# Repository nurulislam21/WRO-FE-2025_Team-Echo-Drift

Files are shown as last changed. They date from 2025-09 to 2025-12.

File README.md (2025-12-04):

# Team Echo Drift - WRO Future Engineers 2025
Loading Echo Drift Cover Banner...






---

**Welcome** to the official GitHub repository of **Team Echo Drift**!

This project showcases our autonomous robot for **WRO Future Engineers 2025**, built to navigate using only **camera**, **gyro**, and **encoder** data. We implement computer vision with **OpenCV**, **PID control**, and sensor data analysis in **MATLAB** to achieve precise and reliable navigation.

Explore the repository to learn more about our system design, documentation, and code!

# Table of Contents  

---

### Ⅰ. [About the Team](#about-the-team)  
### Ⅱ. [Competition Overview](#competition-overview)  
### Ⅲ. [Our Robot](#our-robot)  
### Ⅳ. [System Architecture](#system-architecture)  
### Ⅴ. [Hardware Components](#hardware-components)  
### Ⅵ. [Software & Algorithms](#software--algorithms)  
### Ⅶ. [CAD & Mechanical Design](#cad--mechanical-design)  
### Ⅷ. [Electronics & Wiring](#electronics--wiring)  
### Ⅸ. [Testing & Validation](#testing--validation)  
### Ⅹ. [Results & Performance](#results--performance)  
### Ⅺ. [Future Improvements](#future-improvements)  
### Ⅻ. [How to Run the Code](#how-to-run-the-code)  
### XIII. [Contributors](#contributors)  
### XIV. [License](#license)  

---
## About the Team  

We’re three young innovators from across Bangladesh, brought together by our love for robotics and tech. We first met as solo competitors sharing ideas, dreams, and soon a vision. That’s how our team was born.

<!-- Noman -->
<table>
  <tr>
    <td>
<h2> Noman - Mechanical Engineering </h2>

Specialized in Mechanical Design with experience in SolidWorks, Fusion 360, for 3D modeling. Strong background in robotics and embedded systems, 
supported by hands-on R&D work. Experience in robotics and embedded systems supports a well-rounded engineering approach, enabling the design of precise, reliable, and integrated mechanical solutions.
<br/> <br/>
_Github: [github.com/nurulislam21](https://github.com/nurulislam21/)_
    </td>
    <td>
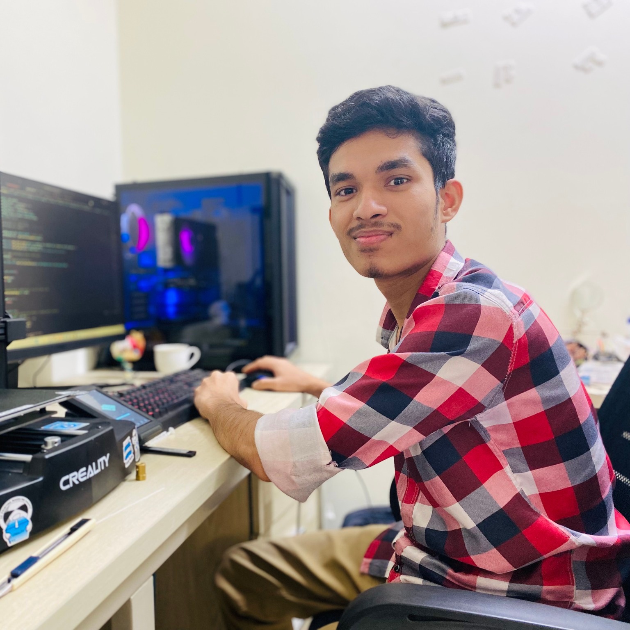
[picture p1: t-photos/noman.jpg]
Nurul Islam Noman
      
    </td>
  </tr>
</table>

<!-- Tanim SK -->
<table>
  <tr>
    <td>
<h2> Tanim - Programming & Software Architecture </h2>

Skilled in Python, C++, JavaScript, OpenCV-based computer vision, Python Matplotlib and NumPy with experience in robotics, embedded systems, Raspberry Pi, microcontrollers, PlatformIO, and building user interfaces (web & tkinter).
<br/> <br/>
_Github: [github.com/tanimsk](https://github.com/tanimsk/)_
    </td>
    <td>
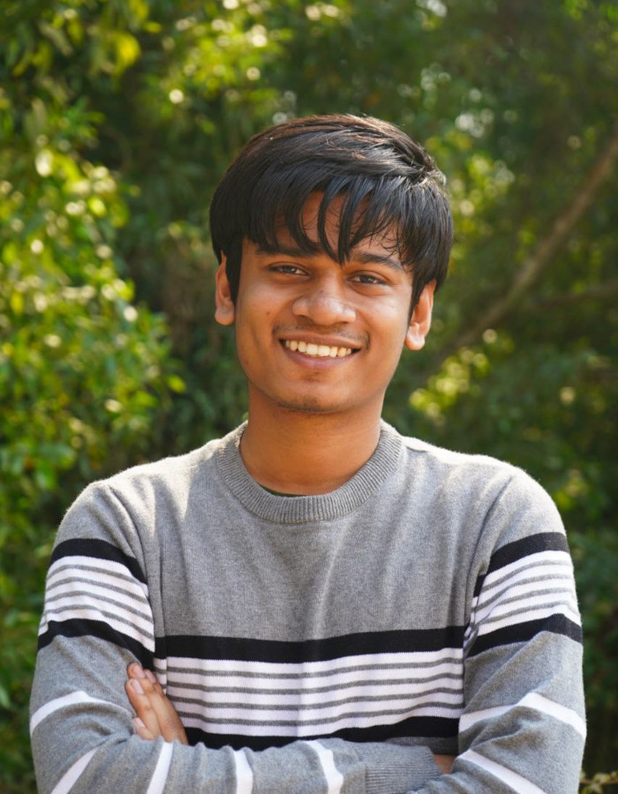
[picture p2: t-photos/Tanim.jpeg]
Tanim SK
      
    </td>
  </tr>
</table>

<!-- Majedul Islam Naeem -->
<table>
  <tr>
    <td>
<h2> Majedul Islam Naeem - Electronics & Circuit Design </h2>

Electronics and circuit design specialist with PCB experience in EasyEDA and Altium. Skilled in etching-based PCB fabrication, soldering, prototyping, troubleshooting, and hardware testing.
<br/> <br/>
_Github: [github.com/majednaeem](https://github.com/majednaeem/)_
    </td>
    <td>
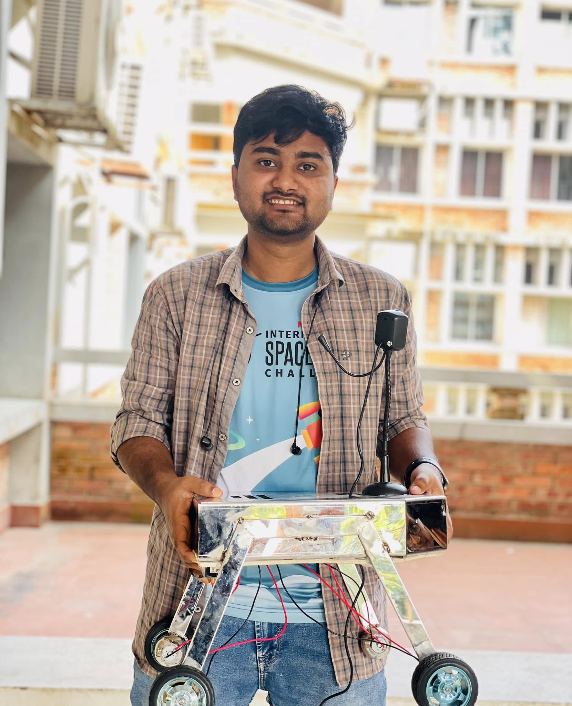
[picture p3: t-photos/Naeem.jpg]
Majedul Islam Naeem
      
    </td>
  </tr>
</table>

---

## Navigation Menu
- [Project Overview](#project-overview)
- [Hardware Design & Gear System](#hardware-design--gear-system)
- [Differential Gear Mechanism](#differential-gear-mechanism)
- [Differential Gear Conversion](#differential-gear-conversion)
- [Software Architecture](#software-architecture)
- [Setup & Dependencies](#setup--dependencies)
- [Video Demonstration](#video)
- [Project Structure](#project-structure)
- [Resources & Media](#resources--media)

---

## Competition Overview  

WRO **Future Engineers** challenges teams to design autonomous electric vehicles (EVs) that can:  

- Navigate track autonomously
- Avoid obstacles and maintain a safe distance from the boundaries
- Parking out and parking out of a designated zone

---

<h2> Competition Rounds </h2>

The WRO Future Engineers 2025 competition is divided into **two progressive rounds**. Each round adds new layers of complexity and pushes teams to demonstrate engineering excellence.  

| Round | Description | Key Tasks | Track Layout |
|:---|:---:|:---|:---|
| **Round 1 - Open Challenge** | Focuses on **precise navigation and lap consistency**. The robot must complete **3 laps** maintaing safe distance from the boundary walls. Judges emphasize **stability, accuracy, and precise lane following**. | - Focus on **stability, accuracy, and smooth lane following**  <br> - Complete **3 full laps** without error | |
| **Round 2 – Obstacle Challenge** |  The robot must avoid **color-coded obstacles** (from specific direction) and then park in a **designated zone** after **3 laps**.| - 🟩 **Green obstacle → move left**  <br> - **🟥 Red obstacle → move right**  <br> -  Maintain speed while **avoiding collisions**   <br> - Finish with **precision parking** inside a marked box  |   |

> **Both rounds are aligned with the [official WRO 2025 Future Engineers Rules (PDF)](https://wro-association.org/wp-content/uploads/WRO-2025-Future-Engineers-Self-Driving-Cars-General-Rules.pdf).**

---

## Our Robot
### Robot Overview  
**Echo Drift** brings a **Vision guided Robot** to WRO 2025, built for speed, accuracy, and adaptability.
  
- Precise track navigation  
- Real-time obstacle avoidance  
- Controlled drift manoeuvres
- Odometry analysis from gyro and encoder

🛠️ 3D-printed chassis | 🔌 Smart sensors & drivers | 🧠 Vision & PID control

---

## 📊 Robot Specifications 

| Parameter | Value |
|---|---|
| *Dimensions* | 20 cm (L) × 11 cm (W) × 25 cm (H) |
| *Weight* | ~ 0.7 kg |
| *Chassis* | Modular 3D-printed PLA with reinforced mounts |
| *Motors* | N20 motor  |
| *Motor Driver* | TB6612FNG dual-channel |
| *Steering* | MG90S Servo |
| *Sensors* | IMU, Encoder |
| *Camera* | OV5647 Fish eye 160° wide angle Camera |
| *Controller* | Raspberry Pi 5 (8GB) |
| *Battery* | 3S 11.1V Li-Po, 2200mAh |
---

## 📸 Vehicle Photos  

| Front | Right | Back |
|---|---|---|
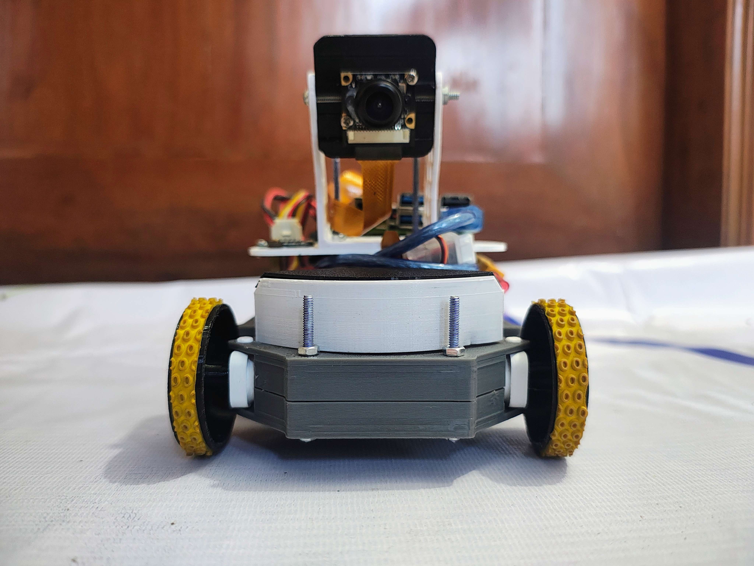
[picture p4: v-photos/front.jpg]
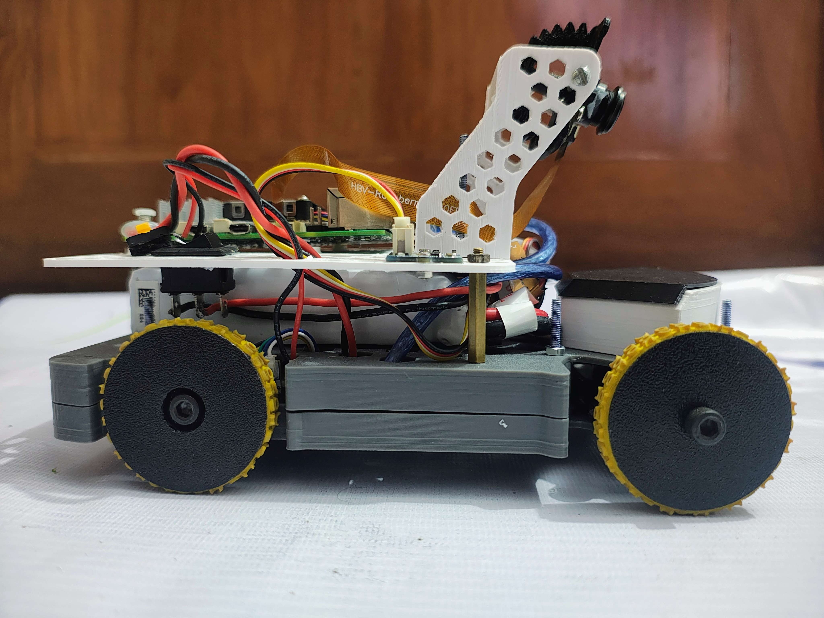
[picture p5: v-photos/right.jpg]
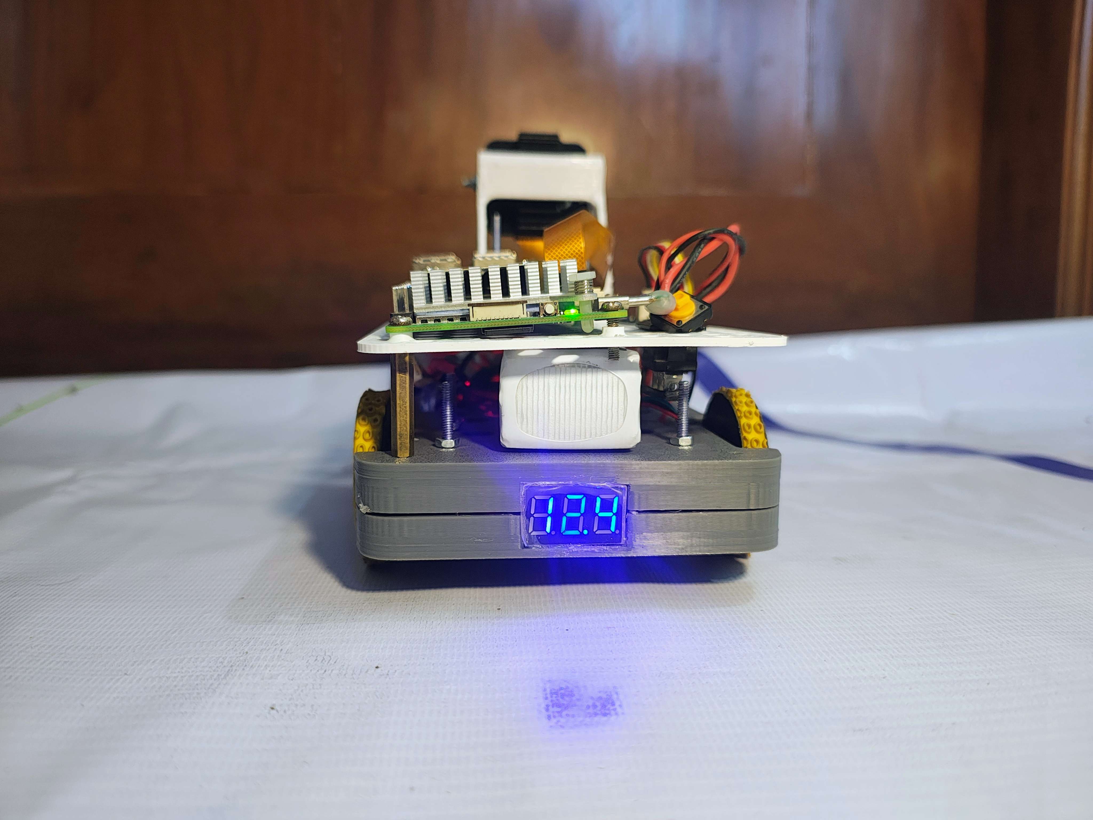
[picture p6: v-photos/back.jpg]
|  |  |  |

| Left | Top | Bottom |
|---|-----|---|
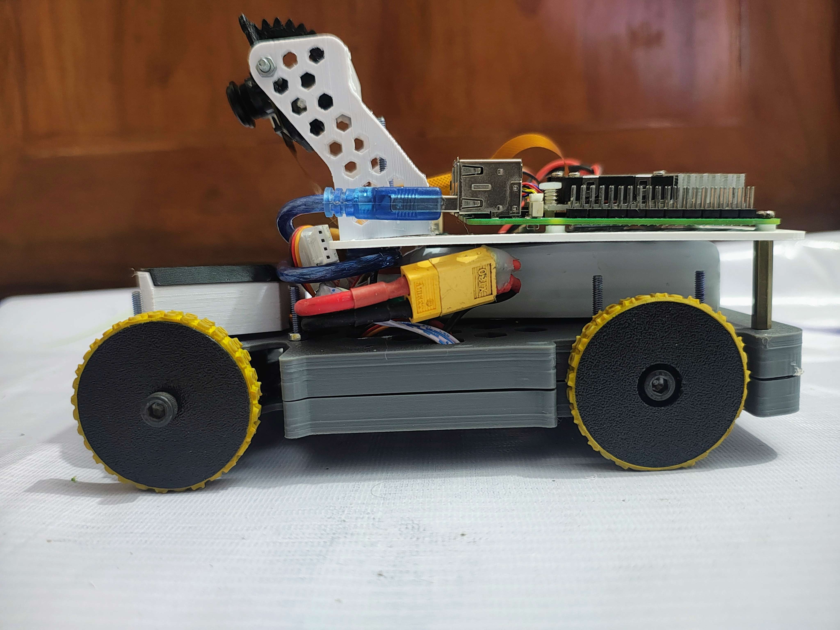
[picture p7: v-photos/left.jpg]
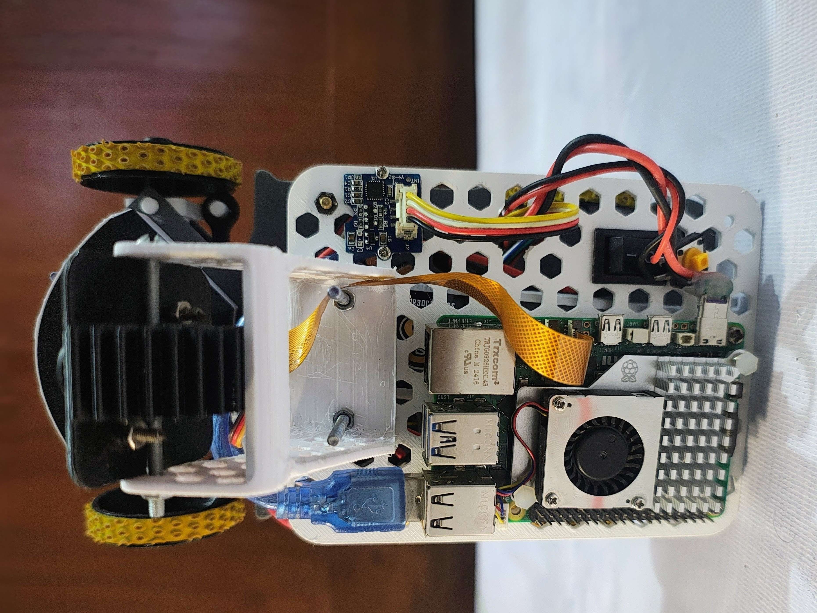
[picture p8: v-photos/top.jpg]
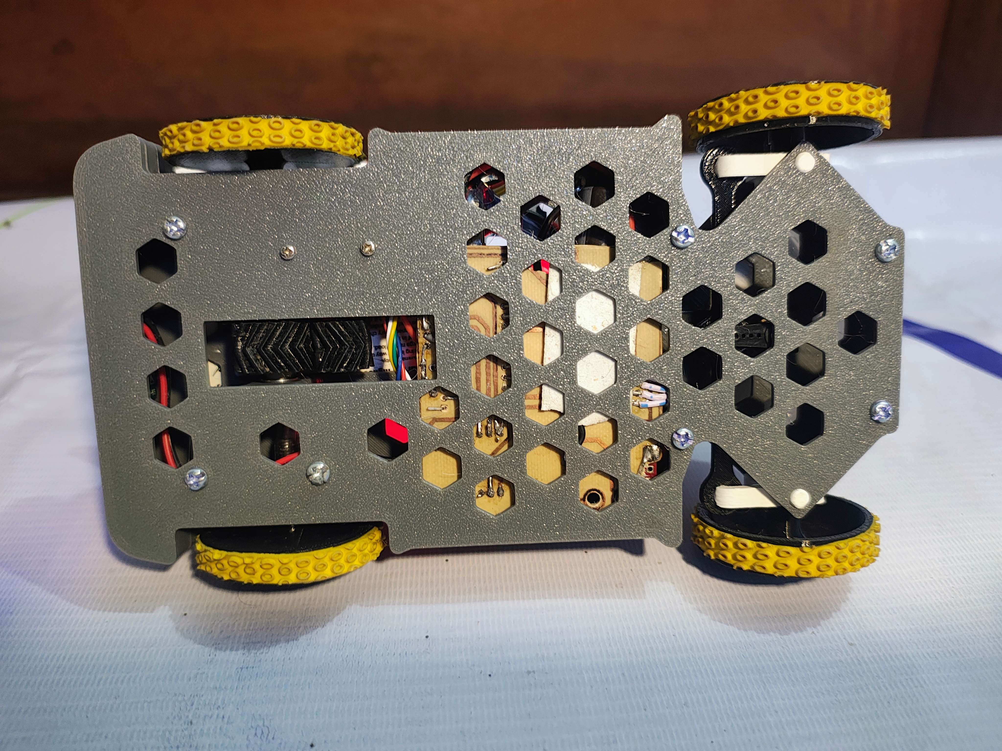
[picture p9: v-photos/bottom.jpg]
|  |  |  |

---

## 🎥 Videos of Our Robot  

Test Run 1 – Track Navigation (https://www.youtube.com/watch?v=hIYXWFPvM-o)

Test Run 2 – Track Navigation, Object avoidance & Parking out (https://www.youtube.com/watch?v=Nrufbg69Ze8)

---

## System Architecture  

  

---

## Layered Architecture Overview 

| *Layer* | *Key Components* | *Role & Engineering Considerations* |
| --- | --- | --- |
| *Hardware* | - PLA + Aluminum Hybrid Chassis  <br> - 1× DC Geared Motors (12V, 600RPM, 1.2Nm)  <br> - High-Torque Servo (15kg·cm)  <br> - 65mm Rubberized Wheels | - Rigid but lightweight frame ensures stability and durability. <br> - Motor torque chosen with ~30% safety margin for acceleration under load. <br> - Servo provides precise steering with quick response. <br> - Wheel diameter selected for a balance between speed and traction. |
| *Power* | - 3S LiPo (11.1V, 2200mAh)  <br> - Power Distribution Board (12V, 5V outputs)  <br> - XT60 Connectors | - LiPo selected for high discharge rate, lightweight, and compact size. <br> - Separate regulated lines prevent voltage drop issues. <br> - XT60 provides short-circuit and overload safety. |
| *Perception* | - Camera <br> - Gyro <br> - Encoder | - Camera handles *lane detection and vision-based markers*. <br> - IMU improves orientation and stability on turns. <br> - Encoders provide real-time speed & distance for closed-loop control. |
| *Control & Processing* | - Raspberry Pi 5 (Python + OpenCV)  <br> - Arduino Nano (C++)  <br> - UART Serial Link | - Pi processes camera input & makes high-level decisions. <br> - Arduino handles *PWM signals, interrupts, and motor control* with real-time precision. <br> - UART ensures fast, low-latency communication between subsystems. |
| *Decision* | - OpenCV Line Detection  <br> - Sensor Fusion (Camera)  <br> - PID Steering Control  <br> - Encoder-based Speed Feedback  <br> - Emergency Stop Failsafe | - Lane tracking optimized with *real-time vision algorithms*. <br> - Sensor fusion improves obstacle avoidance accuracy. <br> - PID ensures smooth steering corrections. <br> - Encoders maintain consistent velocity. <br> - Safety protocol: robot halts when conflicting data is detected. |
| *Actuation* | -  Motor Driver <br> - PWM Servo Driver | - H-Bridge supplies bidirectional control for drive motors. <br> - Servo driver ensures precise angle control. <br> - Final output: *smooth differential drive with adaptive steering*. |
---

## Threads & Rates
| Task | Rate | Notes |
| --- | ---: | --- |
| Sensor read  |  50–100 Hz | median filter, timeouts |
| Vision |  20–30 FPS | HSV masks for lane & pillar colors |
| Fusion | 50 Hz | complementary/Kalman (optional) |
| Navigation | 20–50 Hz | lane-keeping, color rule, parking  |
| Control | 100–200 Hz | PID for speed + steering |

---

## Hardware & Mechanical Part
Our robot is designed with a balanced mix of mechanical, electrical, and electronic components, ensuring rule compliance (size, weight, drive system) and performance (precision, stability, obstacle avoidance).

### List of components

| Component | Image | Qty | Notes |
|---|---|-----|---|
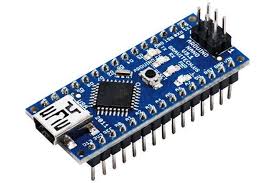
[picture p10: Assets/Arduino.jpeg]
| **Arduino Nano** |  | x1 | Microcontroller for low-level control |
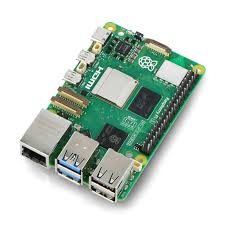
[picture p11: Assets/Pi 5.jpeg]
| **Raspberry Pi 5** |  | x1 | Main controller for vision & navigation |
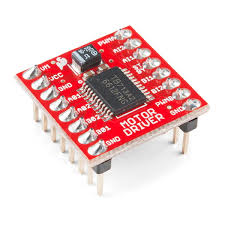
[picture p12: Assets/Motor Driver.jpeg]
| **TB6612FNG Motor Driver** |  | x1 | Controls DC motors |
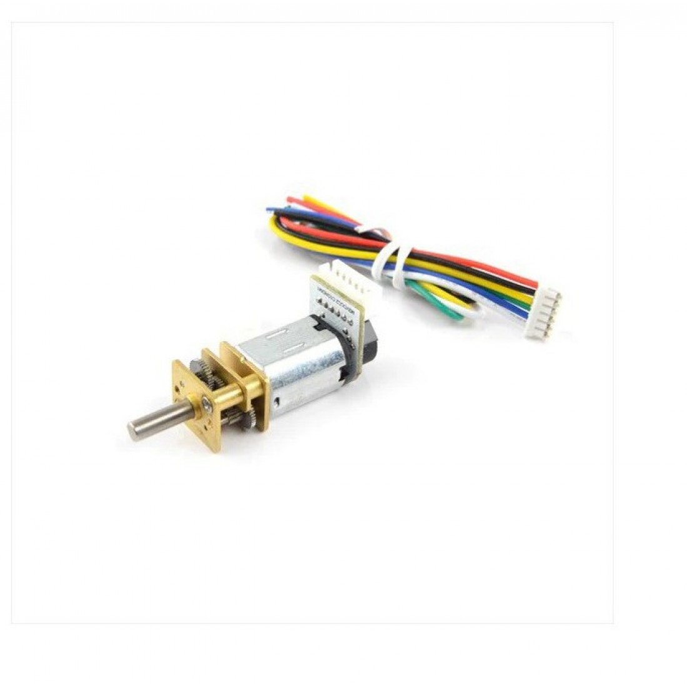
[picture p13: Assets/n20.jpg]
| **N20 DC Gear Motors (12V) with encoder** |  | x2 | Linked to rear axle |
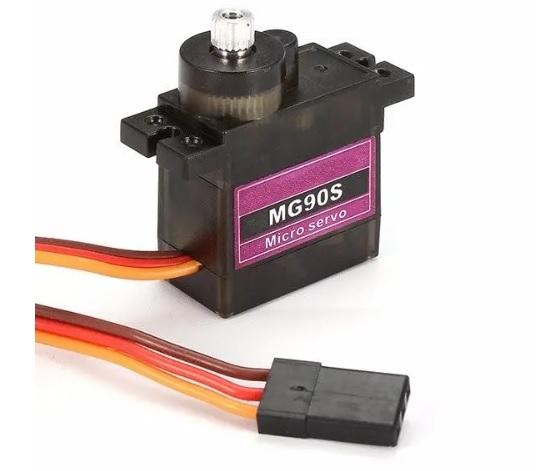
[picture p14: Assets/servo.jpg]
| **MG90s Servo** |  | x1 | For front wheel steering |
| **IMU MPU6050 Gyroscope** |  | x1 | Orientation & stability |
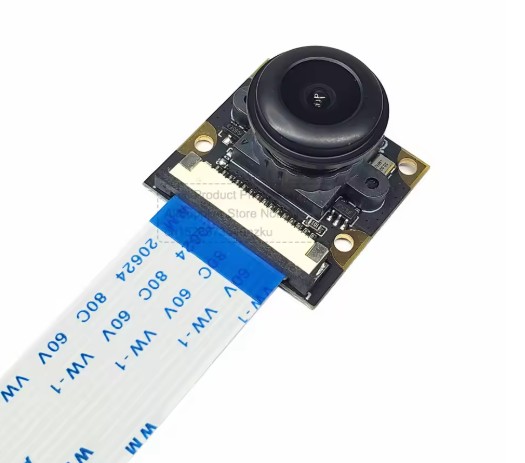
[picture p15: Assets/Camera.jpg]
| **OV5647 Camera Module for Raspberry Pi** |  | x1 | Lane & obstacle detection |
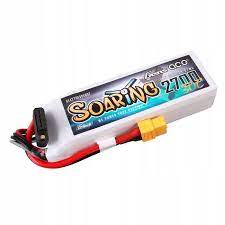
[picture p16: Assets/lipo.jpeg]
| **Li-Po Battery (3S, 11.1V, 2200mAh)** |  | x1 | Main power source |
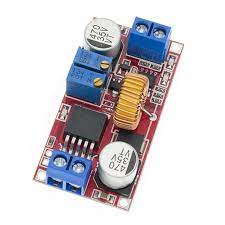
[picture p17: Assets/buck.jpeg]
| **XL4015 Step-down Converter** |  | x1 | Voltage regulation |
| **Prototype PCB Board** | PCB | x1 | Custom wiring layout |
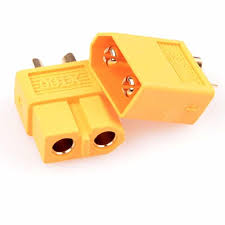
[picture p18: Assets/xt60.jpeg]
| **XT60 Connector** |  | x1 |  Main power control |
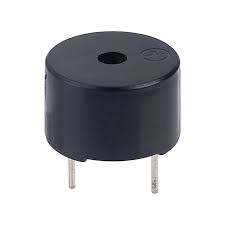
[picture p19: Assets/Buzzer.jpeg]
| **Buzzer** |  | x1 |Line Status Check |

## Mobility Management
Mobility management defines how the robot moves, steers, and maintains stability. For Echo Drift, we adopted a rear-wheel drive + front servo steering configuration. This gives better maneuverability, efficient obstacle avoidance, and realistic car-like motion.

### Motor Selection 

#### Drive Motors
- **Type:** N20 DC Geared Motors with Encoders  
- **Specs:** 12V, ~600 RPM, ~1.2 Nm torque  
- **Reason:** Higher speed compared to 300 RPM version. Encoders provide feedback for closed-loop control (speed & distance). Torque margin (~30% extra) ensures reliable acceleration.

#### Steering Servo
- **Type:** High-torque Servo (~1.8 kg·cm)  
- **Reason:** Quick, precise steering even under load.

#### Engineering Principle
Torque Required = Wheel Radius × Force (Load + Friction)

- Our calculation showed motor Required torque ≈ **0.9 Nm**  
- Selected N20 motors rated ≈ **1.2 Nm** → safe margin  
- Speed doubles from ~1.0 m/s (300 RPM) to ~2.0 m/s (600 RPM) on 45 mm wheels.

📂 Encoders connected to Arduino for speed control and stability.

| Drive Motors (N20 with Encoders) | Steering Servo Assembly |
|---|---|
| | |

## Hardware Design & Gear System

The hardware design balances **mechanical precision** with **reliable electronics**.

**Key features:**
- **Drive System:** N20 encoder motor + TB6612FNG driver for smooth torque

- **Steering:** Parallel steering system with MG90S servo for steering control  
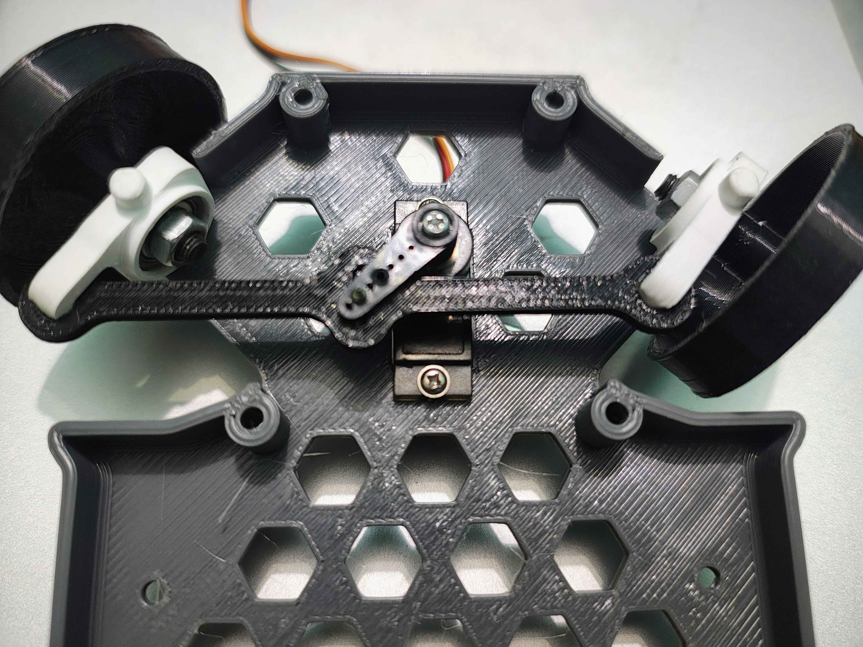
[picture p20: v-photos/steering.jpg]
Steering


- **Differential Gear:** WL Toys differential gear with bearing
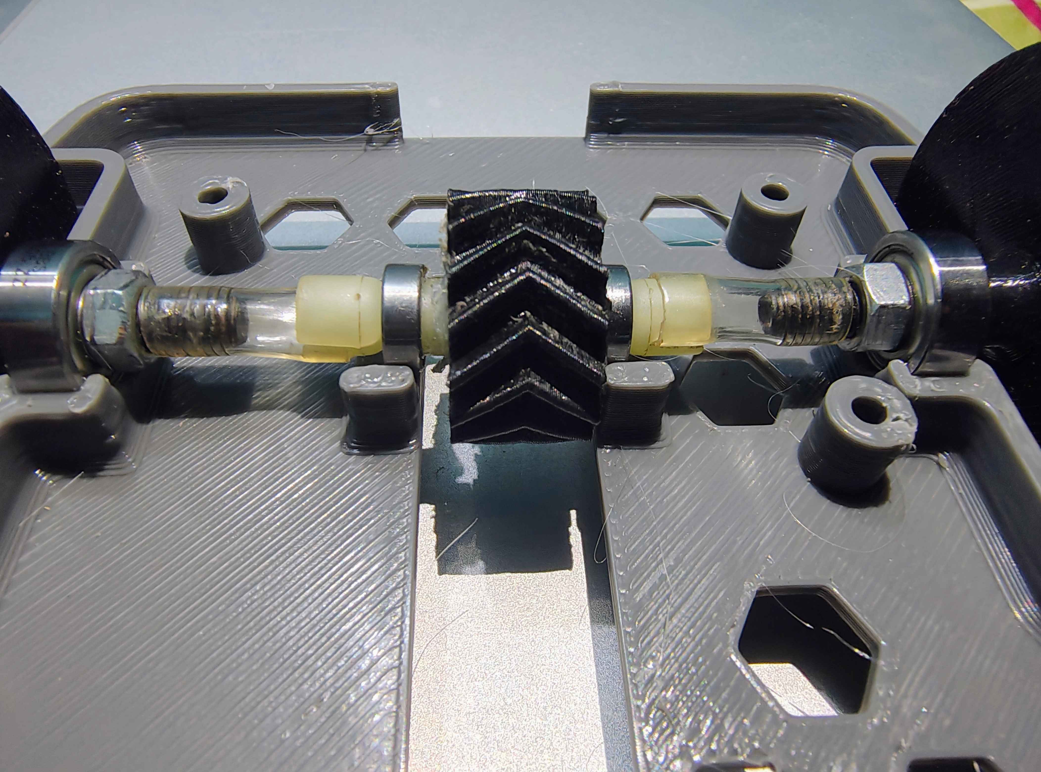
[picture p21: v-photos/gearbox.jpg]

  
- **Chassis:** Fully 3D-printed (SolidWorks STL); lightweight yet strong
SolidWorks Design
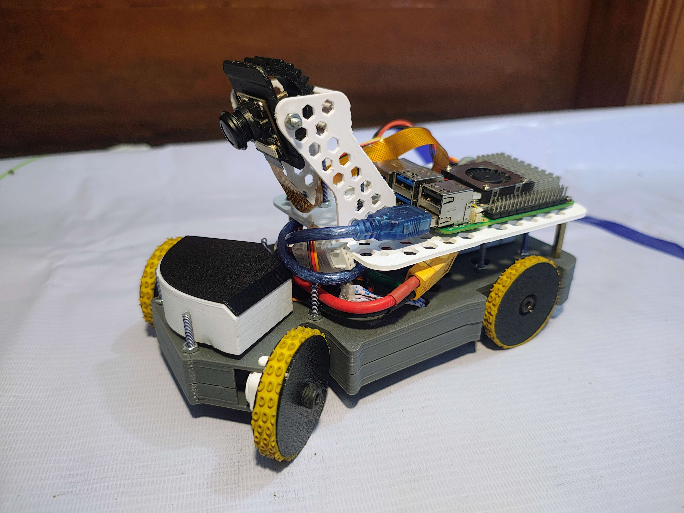
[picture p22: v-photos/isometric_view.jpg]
Vehicle Side View


- **ND filter for camera**: We later mounted an ND filter in front of the camera to maintain consistent lighting in bright environments. By tuning the ND filter, we were able to reduce glare and stabilize exposure, ensuring more reliable image processing.
<p align="center">
  
  
</p>

---

## Software Architecture

<p align="center">
  Software Flowchart
</p>

---

## Setup & Dependencies

| Category | Details |
|---|---|
| **Operating System** | Raspberry Pi OS, Ubuntu 20.04 |
| **Programming Languages** | C, C++, Python |
| **Compiler** | GCC |
| **Libraries (C/C++)** | WiringPi, bcm2835 |
| **Build Tools** | Make, GCC toolchain |
| **Python Packages** | simple-pid, opencv-python, numpy, matplotlib, pillow, pyserial |
| **Arduino Development Platform** | PlatformIO |

**Install Dependencies:**
```bash
sudo apt update && sudo apt upgrade -y
sudo apt install build-essential git make -y

# WiringPi
git clone https://github.com/WiringPi/WiringPi
cd WiringPi && ./build && cd ..

# bcm2835
wget http://www.airspayce.com/mikem/bcm2835/bcm2835-1.71.tar.gz
tar zxvf bcm2835-1.71.tar.gz
cd bcm2835-1.71
./configure && make
sudo make check
sudo make install
cd ..

# clone our repository
git clone https://github.com/nurulislam21/WRO-FE-2025_Team-Echo-Drift/
cd WRO-FE-2025_Team-Echo-Drift/src
# install the dependencies
pip install -r requirements.txt

# run the program
# for open challenge
python raspberrypi/open_challenge.py --debug

# for obstacle challenge
python raspberrypi/obstacle_challenge.py --debug

# for starting the program on startup, register it as a service or a crontab

```

We have divided the whole frame into 6 segments, each segment runs a seperate image processing thread.

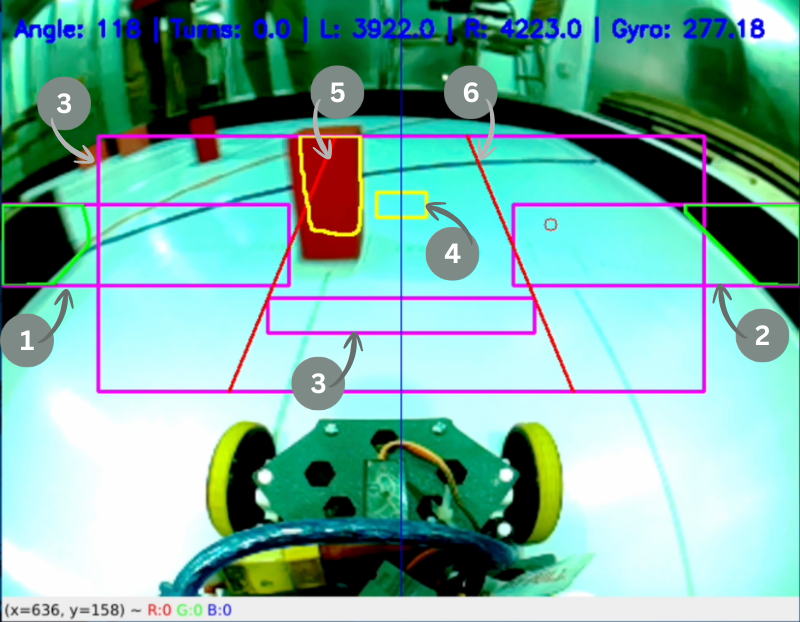
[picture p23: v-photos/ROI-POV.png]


ROI Partition Explanation:
```
1. Left Wall Region: Detects the left boundary wall for lane-keeping.
2. Right Wall Region: Detects the right boundary wall for lane-keeping.
3. Reverse Region: Detects if obstacles/walls are too close.
4. Front wall Region: Detects frontal wall.
5. Left Danger Zone: Monitors for red obstacles on the right side.
6. Right Danger Zone: Monitors for green obstacles on the left side.
```

The frame regions are assigned here:

```py
# Region of Interest coordinates
LEFT_REGION = [20, 220, 270, 280]
RIGHT_REGION = [370, 220, 620, 280]
OBS_REGION = [85, 140, 555, 320]
REVERSE_REGION = [233, 300, 407, 320]
FRONT_WALL_REGION = [300, 195, 340, 215]
PARKING_LOT_REGION = [0, 185, CAM_WIDTH, 400]
DANGER_ZONE_POINTS = [
    {
        "x1": 302,
        "y1": OBS_REGION[1],
        "x2": 205,
        "y2": OBS_REGION[3],
    },
    {
        "x1": 350,
        "y1": OBS_REGION[1],
        "x2": 435,
        "y2": OBS_REGION[3],
    },
]
```

<br>

We are using LAB colors for detecting a object based on a certain color range, the color ranges are assigned as numpy arrays in [main.py](https://github.com/nurulislam21/WRO-FE-2025_Team-Echo-Drift/blob/main/src/raspberrypi/main.py):

```py
# Color ranges
LOWER_BLACK = np.array([0, 108, 90])
UPPER_BLACK = np.array([89, 148, 163])

LOWER_ORANGE = np.array([135, 125, 83])
UPPER_ORANGE = np.array([195, 165, 123])

LOWER_BLUE = np.array([93, 144, 164])
UPPER_BLUE = np.array([153, 184, 204])

# obstacle color ranges HSV
LOWER_RED = np.array([160, 100, 200])
UPPER_RED = np.array([180, 255, 255])

# HSV
LOWER_GREEN = np.array([35, 100, 50])
UPPER_GREEN = np.array([85, 255, 255])

# parking color ranges
LOWER_MAGENTA = np.array([100, 81, 105])
UPPER_MAGENTA = np.array([170, 121, 145])
```

<br>

Then we made a class called `ContourWorkers.py` in [contour_workers.py](https://github.com/nurulislam21/WRO-FE-2025_Team-Echo-Drift/blob/main/src/raspberrypi/contour_workers.py), this class is used to get contours based on the passed color ranges. ContourWorker starts 6 seperate thread for 6 regions, and processes them individually. Thus we are able to keep a decent FPS (around 25) while our bot is on the go. We are using `Queue` with size of 2 to make sure our frames are queued and passed to the thread and processed accordingly:

```py
# queues
self.frame_queue_left = Queue(maxsize=2)
self.frame_queue_right = Queue(maxsize=2)
self.frame_queue_orange = Queue(maxsize=2)
self.frame_queue_blue = Queue(maxsize=2)
self.frame_queue_green = Queue(maxsize=2)
...
```

<br>

After that, we were facing an issue for motion blur due to speed. We've resolved this issue by setting explicit `Exposure rate` and `Analogue gain`, and disabling `Auto Exposure` & `Auto white balance` in our camera configuration:



<br>

```py
picam2.set_controls(
    {
        "ExposureTime": 16000,
        "AnalogueGain": 42.0,
        "AeEnable": False,
        "AwbEnable": False,
        "FrameDurationLimits": (40000, 40000),
    }
)
```

<br>

After the program is executed, we start 6 threads, and inside while loop, we are collecting the contour result in each iteration:

```py
# Retrieve all results from queues (non-blocking)
(
    left_result,
    right_result,
    green_result,
    red_result,
    reverse_result,
    front_wall_result,
) = contour_workers.collect_results()
```

<br>

We are using PID steering, and for the sake of simplicity, we've used [python simple-pid](https://pypi.org/project/simple-pid/). We've made a tool [adjust_pid_values.py](https://github.com/nurulislam21/WRO-FE-2025_Team-Echo-Drift/blob/main/src/raspberrypi/adjust_pid_values.py) for adjusting the Kp, Ki, and Kd values.



<br>

We are comparing the area of left region and right region, and normalizing the error to range `[-1, 1]`.  If the left area is greater than right area the bot tends to turn right and vice versa



```py
right_area_normalized = np.interp(
    right_area,
    [0, BLACK_WALL_DETECTOR_AREA / 2, BLACK_WALL_DETECTOR_AREA],
    [0, 0.7, 1],
)
left_area_normalized = np.interp(
    left_area,
    [0, BLACK_WALL_DETECTOR_AREA / 2, BLACK_WALL_DETECTOR_AREA],
    [0, 0.7, 1],
)
error = right_area_normalized - left_area_normalized
normalized_angle_offset = pid(error)
```

<br>

For Lap detection & steering in tight spaces, we are using odometry (getting xy coords from encoders and gyro)

odometry

**Lap detection strategy**: We track an imaginary inner and outer rectangle using odometry. A starting-region rectangle marks the lap point. When the robot re-enters this region after a time threshold, a lap is counted. After three laps, the robot stops.



**Tight-Space cornering Strategy**: In narrow corners, visual navigation alone is insufficient because the black wall directly ahead blocks reliable image-based guidance. To handle this, we incorporate odometry to estimate the robot’s position relative to the outer and inner boundaries.

For clockwise laps, the robot turns right when it approaches the outer boundary, and left when it gets too close to the inner boundary. For counterclockwise laps, the logic is reversed. This ensures smooth cornering even in visually challenging tight spaces.



We implemented the odometry system in a dedicated Python class. The complete implementation — including position tracking, orientation updates, and boundary detection — can be found here:  
**[odometry.py](https://github.com/nurulislam21/WRO-FE-2025_Team-Echo-Drift/blob/main/src/raspberrypi/odometry.py)**

To draw this odometry, we've collected some data of encoder ticks and gyro angle by running our bot on the track few times, and made `csv` files.
For analyzing the values, we've used [MATLAB](https://www.mathworks.com/)



The csv file format was:
| **ticks** | **angle** |
|---|---|
| Encoder ticks | Gyro angle |
| ... | ... |

Then we've discovered that, the bot was drifting away, due to mechanical error, after that we have used [Moving Average](https://en.wikipedia.org/wiki/Moving_average) realtime with the previous lap data, and hence 
calculated the drift of xy coordinates. After that, we substracted these values to omit the drift.

Matlab code can be found here:
**[src/data_analysis](https://github.com/nurulislam21/WRO-FE-2025_Team-Echo-Drift/tree/main/src/data_analysis)**

<br>

For obstacle avoidance, we use a pivot point as the target.
- For a red object, the pivot is the midpoint between the object’s x-coordinate and the right wall’s centroid x-coordinate.
- For a green object, the pivot is the midpoint between the object’s x-coordinate and the left wall’s centroid x-coordinate.

The pivot is calculated only when the objects enter the danger zone; otherwise, it is ignored.



```py
r_wall_x, r_wall_y = get_overall_centroid(right_result.contours)

if r_wall_x is None:
    print("No wall detected!")
    # set default wall position if none detected
    r_wall_x = CAM_WIDTH
else:
    # transform to global coordinates
    r_wall_x += RIGHT_REGION[0]

# transform to global coordinates
red_obj_x += OBS_REGION[0]
red_obj_y += OBS_REGION[1]

# compute how far is the bot from the object and walls middle point
offset_x = (red_obj_x + ((r_wall_x - red_obj_x) // 2)) - (
    CAM_WIDTH // 2
)

# show a circle dot on the middle of the object and wall
obstacle_wall_pivot = (
    red_obj_x + ((r_wall_x - red_obj_x) // 2),
    red_obj_y,
)

obj_error = offset_x / (CAM_WIDTH // 2)  # normalized [-1, 1]
```

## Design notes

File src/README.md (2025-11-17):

## Folder Structure
```
.
│
├── arduino
│   ├── ITG3200_gyro_test
│   │   └── ITG3200_gyro_test.ino
│   ├── platformio.ini
│   └── src
│       └── main.cpp
│
├── raspberrypi
│   ├── __init__.py
│   ├── adjust_pid_values.py
│   ├── camera_settings.json
│   ├── contour_workers.py
│   ├── img_processing_functions.py
│   ├── main.py
│   ├── odometry_log.py
│   ├── odometry_sample_generator.py
│   ├── odometry.py
│   ├── parking.py
│   ├── playground.py
│   ├── requirements.txt
│   └── test.py
├── requirements.txt
│
│
└── tools
    ├── adjust_camera_settings.py
    ├── camera_settings.json
    ├── car_driving.py
    ├── color_picker.py
    ├── color_ranges.json
    ├── contour_analysis.py
    ├── danger_zone_visualizer.py
    ├── masking_test_pi.py
    ├── masking_test.py
    └── record.py    
```

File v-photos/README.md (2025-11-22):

| Front | Right | Back |
|---|---|---|
|  |  |  |

| Left | Top | Bottom |
|---|-----|---|
|  |  |  |

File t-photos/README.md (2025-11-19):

Team's photos
====

We, the members of this team, took this photo just before the national round of WRO.
<br>

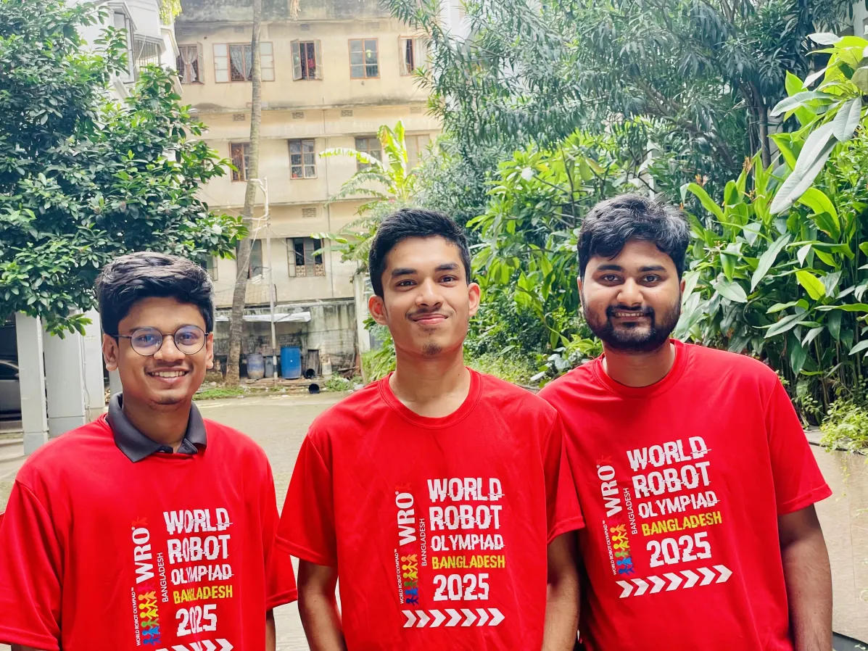
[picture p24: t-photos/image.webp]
Team Photo


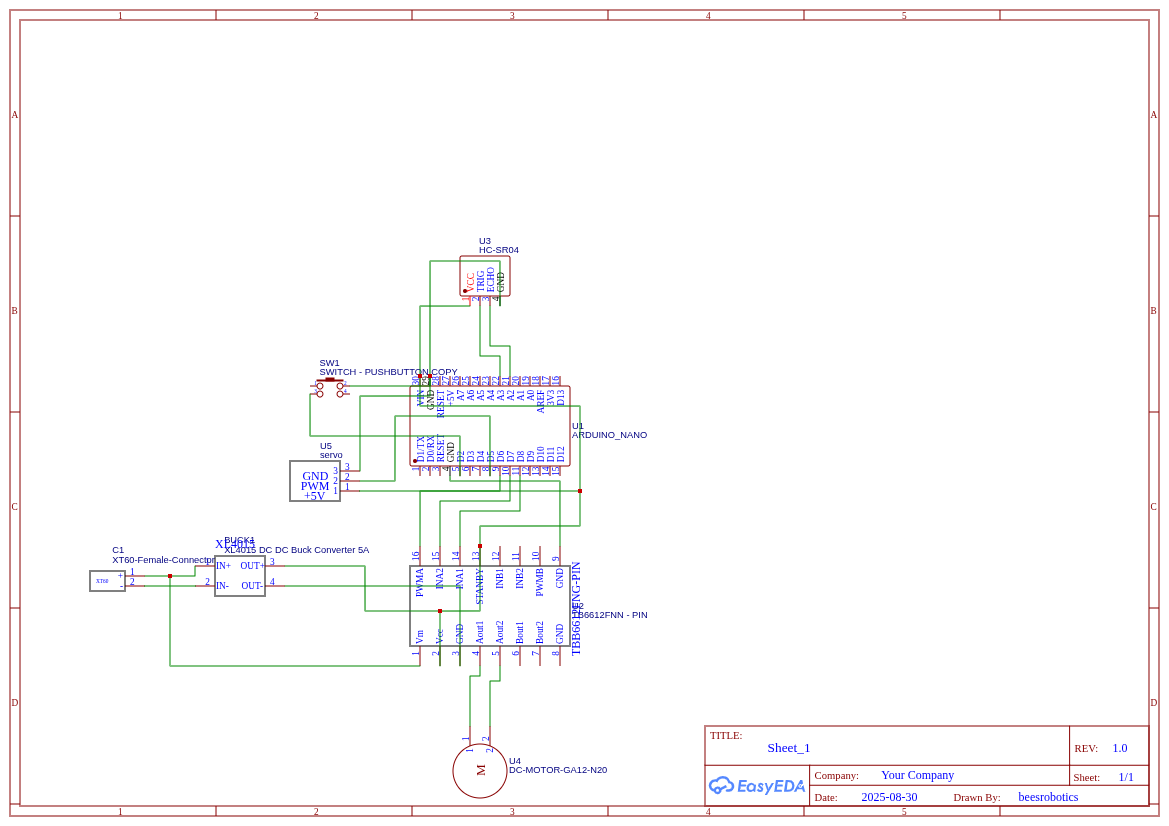
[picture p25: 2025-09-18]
schemes/Schematic_WRO-echo-drift_2025-09-19.png

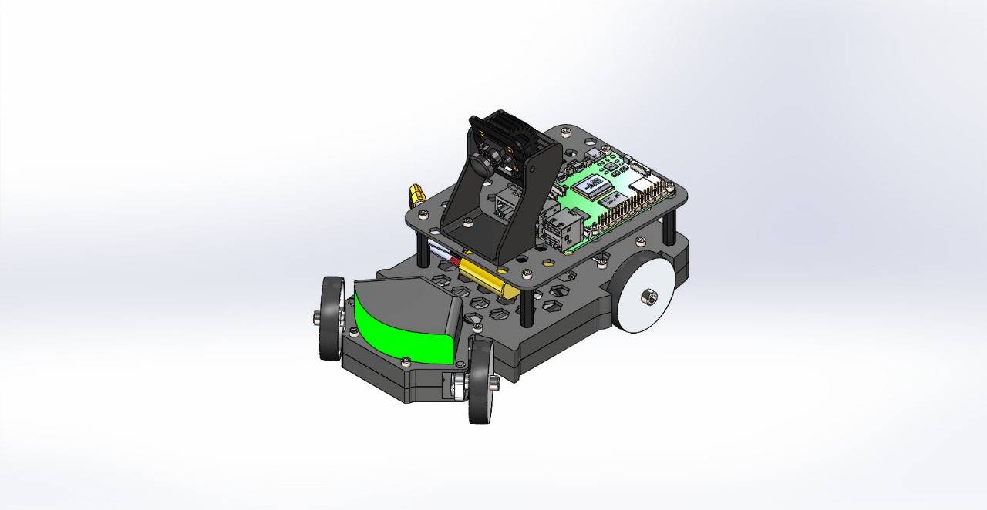
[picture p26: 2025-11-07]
v-photos/cad_design_isometric_view.jpeg

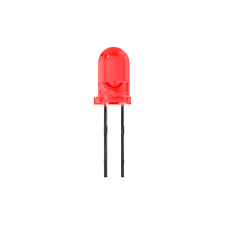
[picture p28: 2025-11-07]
Assets/Led.png

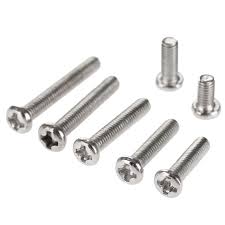
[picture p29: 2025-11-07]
Assets/screw.jpeg

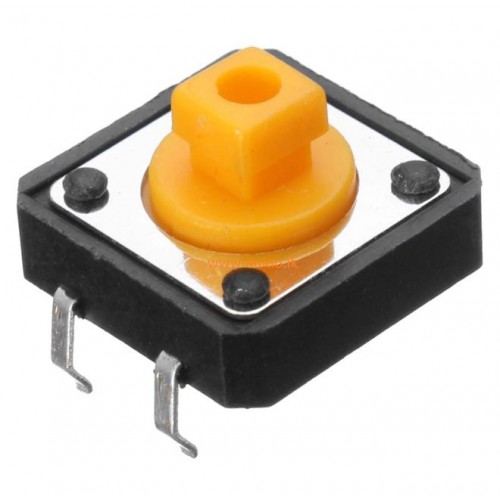
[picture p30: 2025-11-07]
Assets/Push-Button.jpg

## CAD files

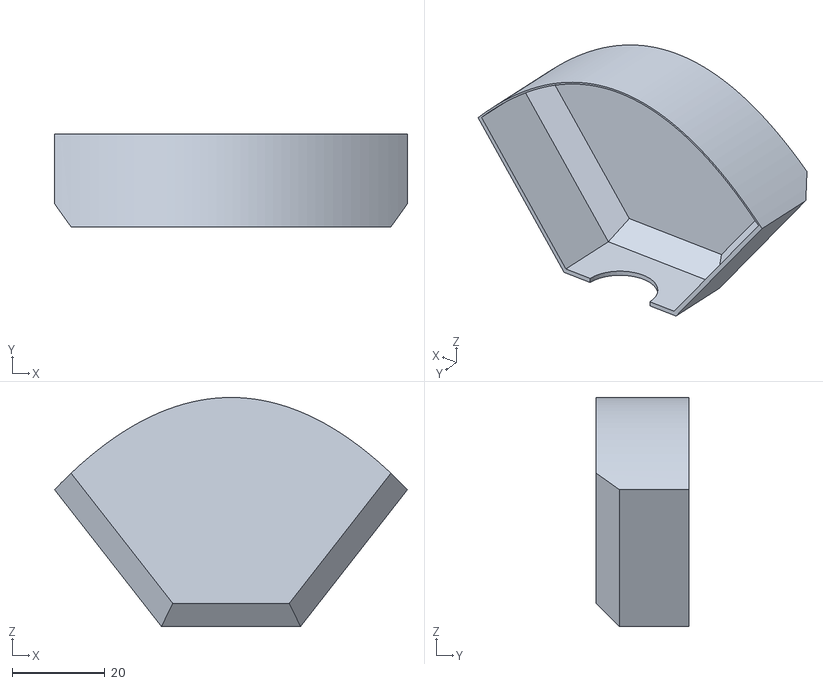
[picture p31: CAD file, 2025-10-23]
models/LED_cover.STL
76.1 x 20.0 x 49.4

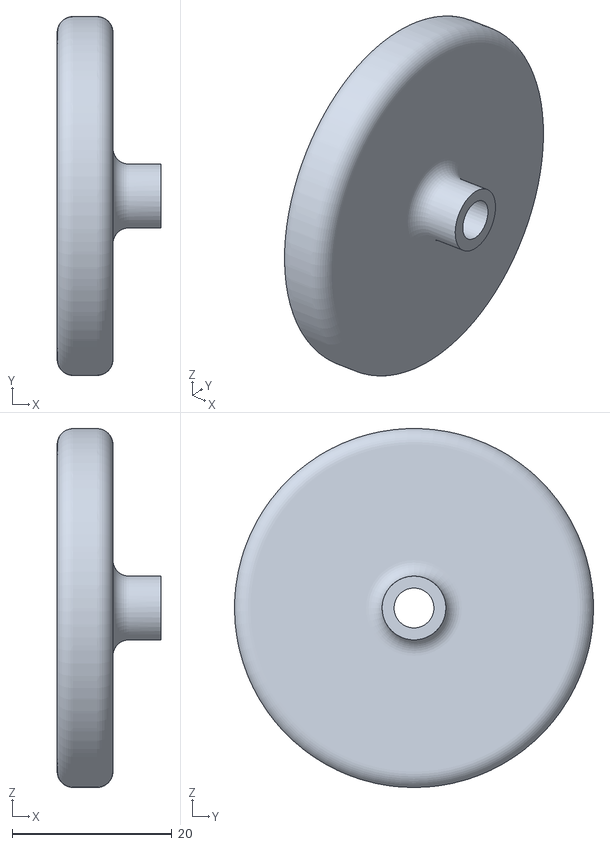
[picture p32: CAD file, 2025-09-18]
models/V1_Models/back wheel 1.STL
13.0 x 45.0 x 45.0

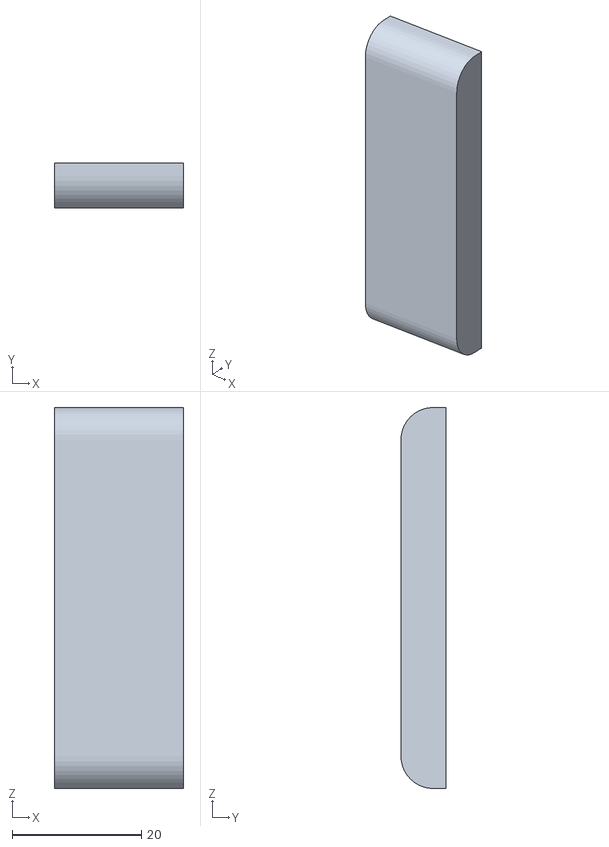
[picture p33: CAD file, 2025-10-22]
models/Part2_gearcover.STL
20.0 x 7.00 x 59.0

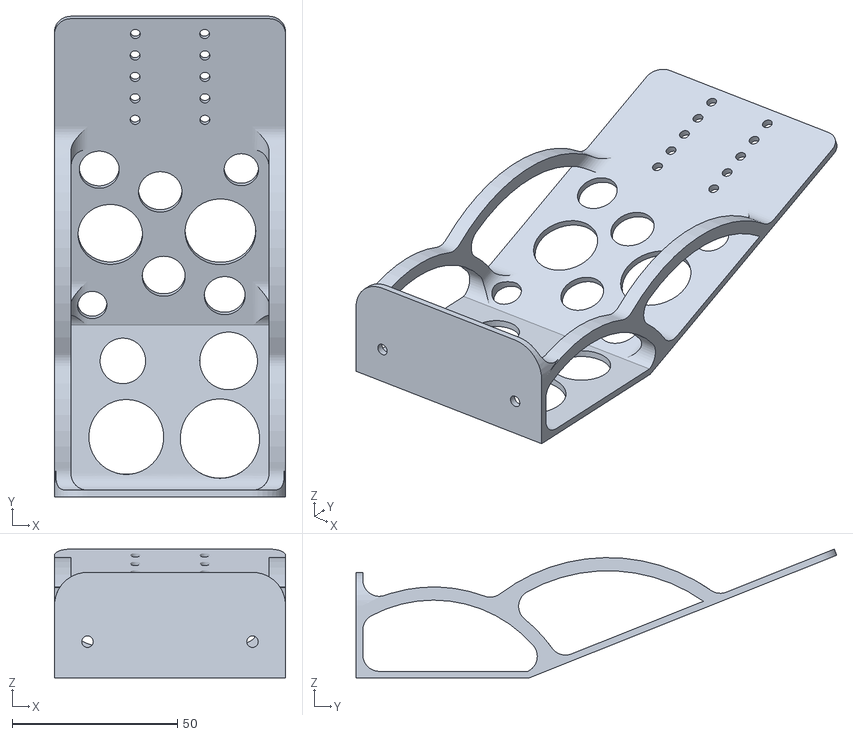
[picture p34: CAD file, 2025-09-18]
models/V1_Models/Camera holder.STL
70.0 x 145.6 x 39.1

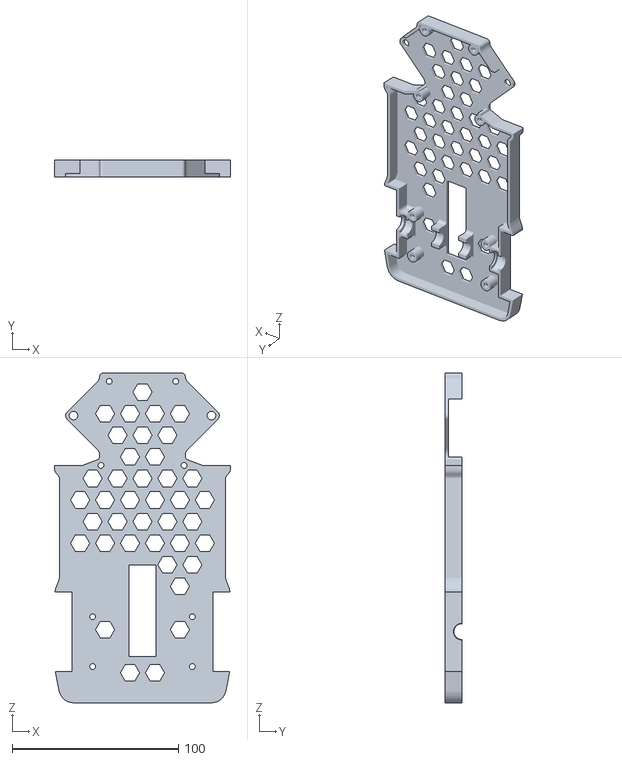
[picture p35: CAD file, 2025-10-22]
models/Part1.STL
106.2 x 10.0 x 198.5

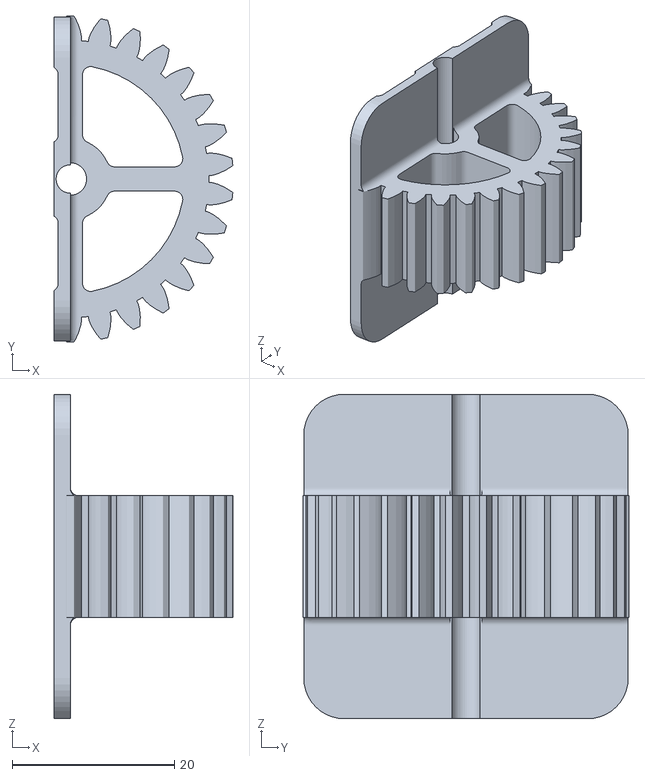
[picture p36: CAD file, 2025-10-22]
models/spur gear for camera mount.STL
22.0 x 40.2 x 40.0

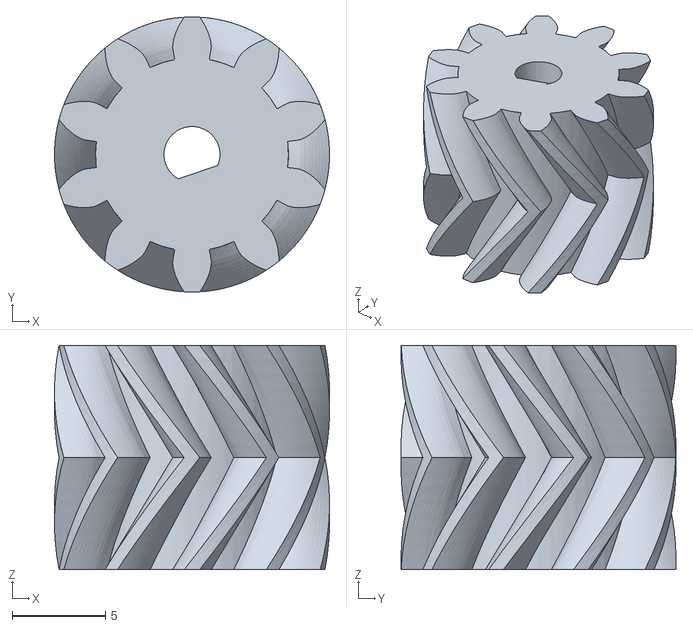
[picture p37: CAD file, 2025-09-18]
models/V1_Models/herringbone motor.STL
14.7 x 14.7 x 12.0

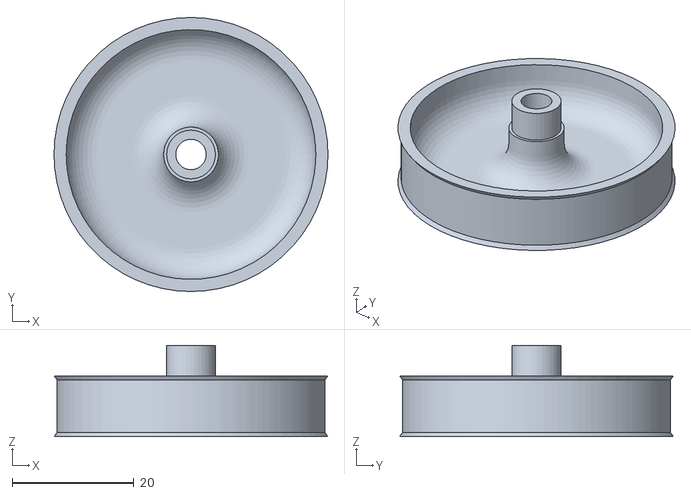
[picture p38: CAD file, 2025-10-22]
models/rearwheel_2pcs.STL
45.0 x 45.0 x 15.0

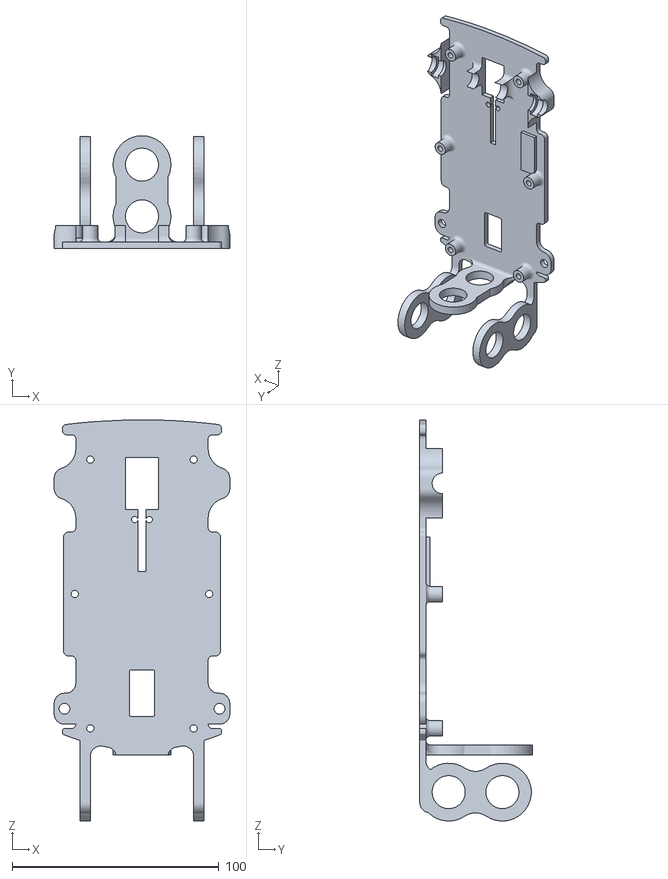
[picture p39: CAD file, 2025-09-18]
models/V1_Models/bottom chassis.STL
85.0 x 54.4 x 194.0

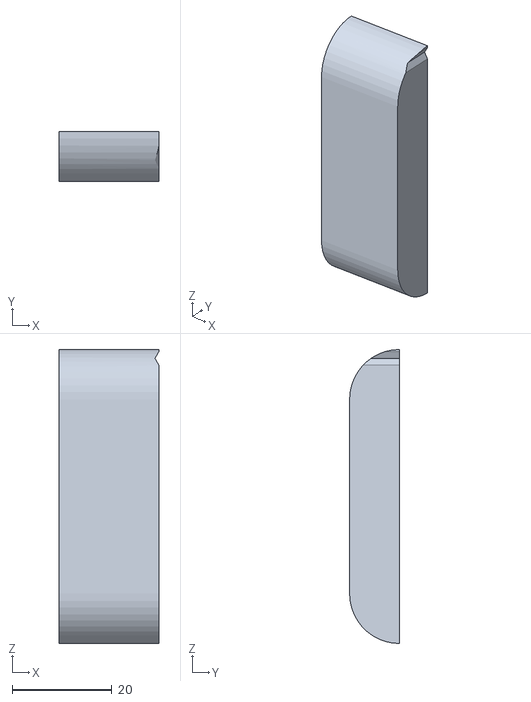
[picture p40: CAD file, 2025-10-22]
models/Part1_gearcover.STL
20.0 x 10.0 x 59.0

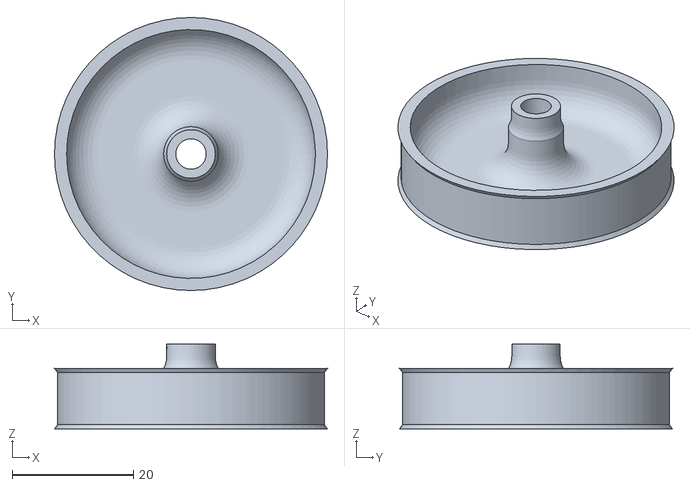
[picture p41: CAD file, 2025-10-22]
models/front_wheel_2pcs.STL
45.0 x 45.0 x 14.0

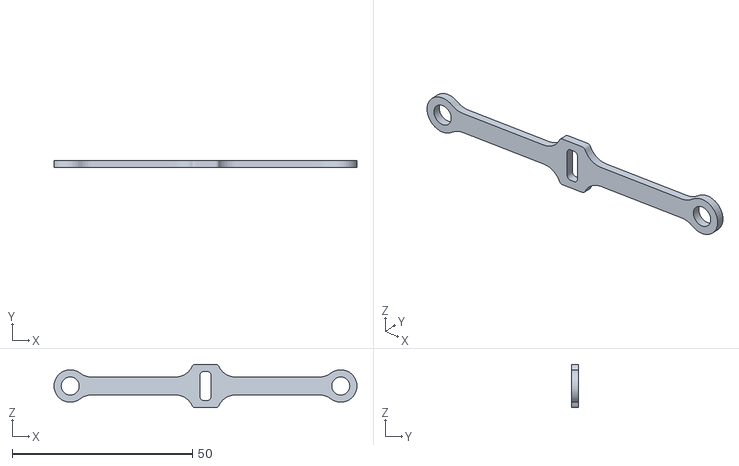
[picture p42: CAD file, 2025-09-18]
models/V1_Models/steering.STL
84.0 x 2.00 x 12.0

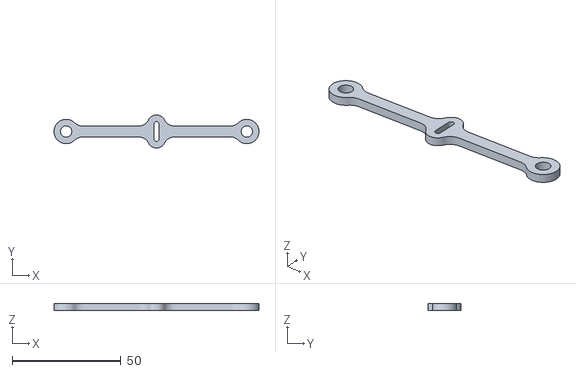
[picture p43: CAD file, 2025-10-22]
models/Steering_Rack.STL
94.2 x 15.2 x 3.00

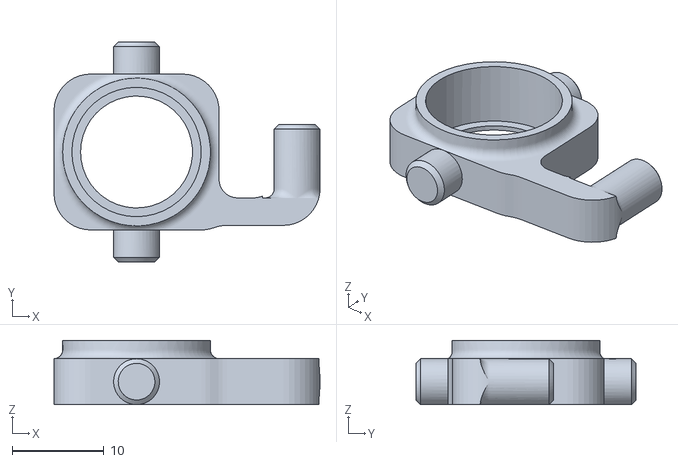
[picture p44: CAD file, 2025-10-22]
models/Right_stearing_knuckles.STL
29.0 x 24.0 x 7.00

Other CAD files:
models/V1_Models/L_font wheel steering.STL
models/V1_Models/L_font wheel.STL
models/V1_Models/R font wheel.STL
models/Left_stearing_knuckles.STL
models/Part2.STL
models/Part4.STL
models/V1_Models/R font wheel steering.STL
models/V1_Models/TOP.STL
models/V1_Models/herringbone gear.STL
models/camera stand.STL

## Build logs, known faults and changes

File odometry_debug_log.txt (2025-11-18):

(4397, 0)
(3459, 0)
(2204, 0)
(942, 0)
(-315, 0)
(-1566, 0)
(-2839, 0)
(-4104, 0)
(-6635, 0)
(-7906, 0)
(-9173, 0)
(-10434, 0)
(-11710, 0)
(-12964, 0)
(-14239, 0)
(-15506, 0)
(-16776, 0)
(-19317, 0)
(-20593, 0)
(-21853, 0)
(-23124, 0)
(-24390, 0)
(-25657, 0)
(-26934, 0)
(-28195, 0)
(-29451, -9.37)
(-31847, -12.18)
(-33111, -16.63)
(-34252, -24.82)
(-35508, -34.51)
(-36684, -36.22)
(-37842, -38.15)
(-38965, -38.65)
(-40140, -38.54)
(-41290, -31.44)
(-43534, -10.43)
(-44705, 0)
(-45862, 0)
(-46999, 0)
(-48114, 0)
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

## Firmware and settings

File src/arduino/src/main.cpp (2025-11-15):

#include <Arduino.h>
#include <Servo.h>
#include <Wire.h>
#include "ITG3200.h"

#define BUTTON_PIN 4 // D4
#define SHARP_IR A4
#define TRIGGER_PIN A2
#define ECHO_PIN A3
#define PWML 11
#define IN1L 6
#define IN2L 7

Servo steeringServo;

int encoderPin1 = 2;            // Encoder Output 'A' must connected with intreput pin of arduino.
int encoderPin2 = 3;            // Encoder Otput 'B' must connected with intreput pin of arduino.
volatile int lastEncoded = 0;   // Here updated value of encoder store.
volatile long encoderValue = 0; // Raw encoder value

unsigned long lastReceivedTime = 0; // Time of last valid serial input
const unsigned long timeout = 1000; // 1 second timeout
int currentAngle = 95;              // Default to 90

int servoMaxLeft = 20;
int servoMaxRight = 170;

// LED Control
#define LED_CONTROL_PIN 13
// Change this: 0=OFF, 1=Full, 2=Medium, 3=Low
int brightnessLevel = 2;

void motor(int speedPercent);
void sw();
void updateGyroTotalAngle();
long getEncoder();
void resetEncoder();
void updateEncoder();
void moveEncoder(int speed, long int steps);
void sendTouch();
void setLampBrightness(int level);

//  --- Gyro ---
ITG3200 gyro;
// Integration & counting
double totalAngle = 0.0; // continuous integrated angle in degrees (can grow + or -)
unsigned long lastTime = 0;

// Filtering / noise suppression
const float FILTER_ALPHA = 0.3f;
float gz_filtered = 0.0f;
const float MIN_RATE_DPS = 3.0f;

long long lastPrintTime = 0;
unsigned long printInterval = 200; // Print every 200 ms

void setup()
{
    Serial.begin(115200);
    steeringServo.attach(5);
    steeringServo.write(currentAngle); // Initialize to 90
    pinMode(BUTTON_PIN, INPUT_PULLUP); // Enable internal pull-up resistor
    pinMode(encoderPin1, INPUT_PULLUP);
    pinMode(encoderPin2, INPUT_PULLUP);

    digitalWrite(encoderPin1, HIGH); // turn pullup resistor on
    digitalWrite(encoderPin2, HIGH); // turn pullup resistor on

    // call updateEncoder() when any high/low changed seen
    // on interrupt 0 (pin 2), or interrupt 1 (pin 3)
    attachInterrupt(0, updateEncoder, CHANGE);
    attachInterrupt(1, updateEncoder, CHANGE);
    // Wait for serial data
    while (!Serial.available())
    {
        delay(10);
    }

    // --- setup the Gyro ----
    Wire.begin();
    delay(200);
    gyro.init();
    delay(200);
    gyro.zeroCalibrate(400, 5);
    lastTime = millis();
    totalAngle = 0.0;
    delay(200);
    // --- End gyro setup ---

    setLampBrightness(brightnessLevel);

    // Once serial is available, perform the servo movement
    steeringServo.write(120);
    delay(500);
    steeringServo.write(60);
    delay(500);
    steeringServo.write(95);
    delay(50);
    sw();
}
void loop()
{
    String inputData = "";
    // Read serial input if available
    while (Serial.available())
    {
        inputData = Serial.readStringUntil('\n');

        // parse space separated values, e.g., "speed,steps,angle"
        char *payload = strdup(inputData.c_str()); // Copy data to mutable string
        String speed = strtok(payload, ",");
        String stepsStr = strtok(NULL, ",");
        String angleStr = strtok(NULL, ",");

        int speedValue = atoi(speed.c_str());
        long int stepsValue = atol(stepsStr.c_str());
        int angle = atoi(angleStr.c_str());

        currentAngle = constrain(angle, servoMaxLeft, servoMaxRight);

        if (stepsValue > 0)
        {
            steeringServo.write(currentAngle);
            delay(100);
            moveEncoder(speedValue, stepsValue);
            delay(100);
            Serial.println("DONE");
        }

        steeringServo.write(currentAngle);
        lastReceivedTime = millis(); // Reset timeout timer

        motor(speedValue);
        free(payload); // Free allocated memory

        if (digitalRead(BUTTON_PIN) == LOW)
        {
            delay(200);
            sw(); // Wait for button press to restart
        }
    }

    // ------- Gyro code -------
    updateGyroTotalAngle();

    // print Steps,totalAngle
    if (millis() - lastPrintTime > printInterval)
    {
        lastPrintTime = millis();
        Serial.print(getEncoder());
        Serial.print(",");
        Serial.println(totalAngle, 2);
    }
    // ------- End gyro code -------

    // Timeout logic: no data received recently
    if (millis() - lastReceivedTime > timeout)
    {
        if (currentAngle != 95)
        {
            currentAngle = 95;
            steeringServo.write(currentAngle);
            Serial.println("No serial input — resetting to 95°");
        }
        motor(-50);
        delay(100);
        motor(0);
        delay(100);
        while (true)
        {
        }
    }
}

void sw()
{
    // Wait for the button to be pressed (goes LOW)
    while (digitalRead(BUTTON_PIN) == HIGH)
    {
        delay(10); // Small delay to reduce CPU load
    }

    // Debounce delay to register the button press
    delay(50);

    // Wait for the button to be released (goes HIGH)
    while (digitalRead(BUTTON_PIN) == LOW)
    {
        delay(10); // Small delay to reduce CPU load
    }

    Serial.println("START");
    // Final debounce delay to ensure clean button release
    delay(50);
}

void motor(int speedPercent)
{
    int speedPWM = constrain((speedPercent * 255) / 100, -255, 255);

    pinMode(PWML, OUTPUT);
    pinMode(IN1L, OUTPUT);
    pinMode(IN2L, OUTPUT);

    if (speedPWM > 0)
    {
        digitalWrite(IN1L, HIGH);
        digitalWrite(IN2L, LOW);
        analogWrite(PWML, speedPWM);
    }
    else if (speedPWM < 0)
    {
        digitalWrite(IN1L, LOW);
        digitalWrite(IN2L, HIGH);
        analogWrite(PWML, -speedPWM);
    }
    else
    {
        digitalWrite(IN1L, LOW);
        digitalWrite(IN2L, LOW);
        analogWrite(PWML, 255); // Brake mode, or stop
    }
}

void updateEncoder()
{
    int state = (PIND >> 2) & 0b11; // read both pins (2 and 3 on UNO)
    int sum = (lastEncoded << 2) | state;
    if (sum == 0b1101 || sum == 0b0100 || sum == 0b0010 || sum == 0b1011)
        encoderValue--;
    else if (sum == 0b1110 || sum == 0b0111 || sum == 0b0001 || sum == 0b1000)
        encoderValue++;
    lastEncoded = state;
}

void resetEncoder()
{
    noInterrupts();
    encoderValue = 0;
    interrupts();
}

long getEncoder()
{
    long val;
    noInterrupts();
    val = encoderValue;
    interrupts();
    return val;
}

void moveEncoder(int speed, long int targetPulses)
{
    resetEncoder();
    motor(speed);

    if (speed > 0)
    {
        while (getEncoder() < targetPulses )
        {
            // update gyro
            updateGyroTotalAngle();
            // print steps and angle
            if (millis() - lastPrintTime > printInterval)
            {
                lastPrintTime = millis();
                Serial.print(getEncoder());
                Serial.print(",");
                Serial.println(totalAngle, 2);
            }
        }
    }
    else
    {
        while (getEncoder() > -targetPulses)
        {
            // update gyro
            updateGyroTotalAngle();
            // print steps and angle
            if (millis() - lastPrintTime > printInterval)
            {
                lastPrintTime = millis();
                Serial.print(getEncoder());
                Serial.print(",");
                Serial.println(totalAngle, 2);
            }
        }
    }
    motor(0);
}

void updateGyroTotalAngle()
{
    // ------- Gyro code -------
    float gx, gy, gz;
    gyro.getAngularVelocity(&gx, &gy, &gz);

    // Time delta
    unsigned long now = micros();
    float dt = (now - lastTime) / 1e6f; // Convert microseconds to seconds
    if (dt <= 0)
        dt = 0.001f;
    lastTime = now;

    // Low-pass filter
    gz_filtered = FILTER_ALPHA * gz + (1.0f - FILTER_ALPHA) * gz_filtered;

    // Ignore tiny rates
    float gz_use = gz_filtered;
    if (fabs(gz_use) < MIN_RATE_DPS)
        gz_use = 0.0f;

    // Integrate angle
    totalAngle += (double)gz_use * dt;
}

void setLampBrightness(int level)
{
  // Now send the right number of pulses for desired level
  // 1 pulse = Full brightness
  // 2 pulses = Medium brightness
  // 3 pulses = Low brightness
  // 0 or 4 pulses = OFF

  if (level > 0 && level <= 3)
  {
    for (int i = 0; i < level; i++)
    {
      sendTouch();
      delay(200);
    }
  }
}

void sendTouch()
{
  pinMode(LED_CONTROL_PIN, OUTPUT);
  digitalWrite(LED_CONTROL_PIN, HIGH);
  delay(50);
  pinMode(LED_CONTROL_PIN, INPUT);
}

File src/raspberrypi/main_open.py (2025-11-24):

import os
import json
import sys
import time
import serial
import cv2
import numpy as np
import threading
from picamera2 import Picamera2
import time
from collections import deque
from img_processing_functions import (
    display_roi,
    get_max_y_coord,
    get_min_x_coord,
    display_debug_screen,
    get_max_x_coord,
    get_overall_centroid,
    point_position,
)
from contour_workers import ContourWorkers
from parking import Parking
from simple_pid import PID
import copy
from odometry import OdometryTracker, OdometryVisualizer, clamp_angle
import math

# debug flag parsing
debug_flag = sys.argv[1] == "--debug" if len(sys.argv) > 1 else ""
if debug_flag:
    DEBUG = True
else:
    DEBUG = False

# DEBUG = True
print("-- DEBUG MODE --" if DEBUG else "-- PRODUCTION --")

# Simulated camera settings
MODE = "NO_OBSTACLE"  # "NO_OBSTACLE" or "OBSTACLE"
CAM_WIDTH = 640
CAM_HEIGHT = 480
MAX_SPEED = 50 if MODE == "OBSTACLE" else 100
MIN_SPEED = 40 if MODE == "OBSTACLE" else 90

# Intersections
TOTAL_LAPS = 3

# Region of Interest coordinates
LEFT_REGION = (
    [0, 165, 230, 230] if MODE == "NO_OBSTACLE" else [0, 165, 230, 230]
)  # left
RIGHT_REGION = (
    [410, 165, 640, 230] if MODE == "NO_OBSTACLE" else [410, 165, 640, 230]
)  # right
LAP_REGION = [215, 260, 415, 305]  # lap detection
OBS_REGION = [77, 110, 563, 355]  # obstacle detection
REVERSE_REGION = [223, 255, 427, 273]  # reverse trigger area
FRONT_WALL_REGION = [300, 160, 340, 180]  # front wall detection
PARKING_LOT_REGION = [0, 185, CAM_WIDTH, 400]  # parking lot detection
# DANGER_ZONE_POINTS = [175, OBS_REGION[1], 465, OBS_REGION[3]]  # area to check for obstacles
DANGER_ZONE_POINTS = [
    {
        "x1": 207,
        "y1": OBS_REGION[1],
        "x2": 77,
        "y2": OBS_REGION[3],
    },
    {
        "x1": 423,
        "y1": OBS_REGION[1],
        "x2": 563,
        "y2": OBS_REGION[3],
    },
]

BLACK_WALL_DETECTOR_AREA = (LEFT_REGION[2] - LEFT_REGION[0]) * (
    LEFT_REGION[3] - LEFT_REGION[1]
)
# OBSTACLE_DETECTOR_X = OBS_REGION[2] - OBS_REGION[0]
# OBSTACLE_DETECTOR_Y = OBS_REGION[3] - OBS_REGION[1]
obstacle_wall_pivot = (None, None)

# Color ranges
# Load color ranges from file
color_ranges = {}
try:
    script_dir = os.path.dirname(os.path.abspath(__file__))
    tools_dir = os.path.join(script_dir, "..", "tools")
    tools_dir = os.path.abspath(tools_dir)
    with open(os.path.join(tools_dir, "color_ranges.json"), "r") as f:
        color_ranges = json.load(f)
except FileNotFoundError:
    print("Color ranges file not found. Using default values.")

# Boundary
LOWER_BLACK = (
    np.array(color_ranges["LOWER_BLACK"])
    if color_ranges["BLACK_COLOR_SPACE"] == "LAB"
    else np.array(color_ranges["LOWER_BLACK_HSV"])
)
UPPER_BLACK = (
    np.array(color_ranges["UPPER_BLACK"])
    if color_ranges["BLACK_COLOR_SPACE"] == "LAB"
    else np.array(color_ranges["UPPER_BLACK_HSV"])
)

# Lane color ranges
LOWER_ORANGE = (
    np.array(color_ranges["LOWER_ORANGE"])
    if color_ranges["ORANGE_COLOR_SPACE"] == "LAB"
    else np.array(color_ranges["LOWER_ORANGE_HSV"])
)
UPPER_ORANGE = (
    np.array(color_ranges["UPPER_ORANGE"])
    if color_ranges["ORANGE_COLOR_SPACE"] == "LAB"
    else np.array(color_ranges["UPPER_ORANGE_HSV"])
)
LOWER_BLUE = (
    np.array(color_ranges["LOWER_BLUE"])
    if color_ranges["BLUE_COLOR_SPACE"] == "LAB"
    else np.array(color_ranges["LOWER_BLUE_HSV"])
)
UPPER_BLUE = (
    np.array(color_ranges["UPPER_BLUE"])
    if color_ranges["BLUE_COLOR_SPACE"] == "LAB"
    else np.array(color_ranges["UPPER_BLUE_HSV"])
)

# Obstacle color ranges
LOWER_RED = (
    np.array(color_ranges["LOWER_RED"])
    if color_ranges["RED_COLOR_SPACE"] == "LAB"
    else np.array(color_ranges["LOWER_RED_HSV"])
)
UPPER_RED = (
    np.array(color_ranges["UPPER_RED"])
    if color_ranges["RED_COLOR_SPACE"] == "LAB"
    else np.array(color_ranges["UPPER_RED_HSV"])
)
LOWER_GREEN = (
    np.array(color_ranges["LOWER_GREEN"])
    if color_ranges["GREEN_COLOR_SPACE"] == "LAB"
    else np.array(color_ranges["LOWER_GREEN_HSV"])
)
UPPER_GREEN = (
    np.array(color_ranges["UPPER_GREEN"])
    if color_ranges["GREEN_COLOR_SPACE"] == "LAB"
    else np.array(color_ranges["UPPER_GREEN_HSV"])
)

# Parking color ranges
LOWER_MAGENTA = (
    np.array(color_ranges["LOWER_MAGENTA"])
    if color_ranges["MAGENTA_COLOR_SPACE"] == "LAB"
    else np.array(color_ranges["LOWER_MAGENTA_HSV"])
)
UPPER_MAGENTA = (
    np.array(color_ranges["UPPER_MAGENTA"])
    if color_ranges["MAGENTA_COLOR_SPACE"] == "LAB"
    else np.array(color_ranges["UPPER_MAGENTA_HSV"])
)

# reverse_black
LOWER_REVERSE_BLACK = LOWER_BLACK
UPPER_REVERSE_BLACK = UPPER_BLACK

contour_workers = ContourWorkers(
    # mode="NO_OBSTACLE",
    color_ranges=color_ranges,
    mode=MODE,
    has_parked_out=False,
    # color ranges
    lower_blue=LOWER_BLUE,
    upper_blue=UPPER_BLUE,
    lower_black=LOWER_BLACK,
    upper_black=UPPER_BLACK,
    lower_reverse_black=LOWER_REVERSE_BLACK,
    upper_reverse_black=UPPER_REVERSE_BLACK,
    lower_orange=LOWER_ORANGE,
    upper_orange=UPPER_ORANGE,
    lower_red=LOWER_RED,
    upper_red=UPPER_RED,
    lower_green=LOWER_GREEN,
    upper_green=UPPER_GREEN,
    upper_magenta=UPPER_MAGENTA,
    lower_magenta=LOWER_MAGENTA,
    # regions
    left_region=LEFT_REGION,
    right_region=RIGHT_REGION,
    lap_region=LAP_REGION,
    obs_region=OBS_REGION,
    front_wall_region=FRONT_WALL_REGION,
    reverse_region=REVERSE_REGION,
    parking_lot_region=PARKING_LOT_REGION,
)

contour_workers.parking_mode = False

STRAIGHT_CONST = 95
turnThresh = 150
exitThresh = 1500

MAX_OFFSET_DEGREE = 55
maxRight = STRAIGHT_CONST + MAX_OFFSET_DEGREE
maxLeft = STRAIGHT_CONST - MAX_OFFSET_DEGREE

# PID controller constants
kp = 1.6 if MODE == "OBSTACLE" else 1.6
ki = 0.0
kd = 0.07
pid = PID(Kp=kp, Ki=ki, Kd=kd, setpoint=0)
pid.output_limits = (-1, 1)  # limit output to -1 to 1
pid.sample_time = 0.02
# SMOOTH_WINDOW = 3
# left_buf = deque(maxlen=SMOOTH_WINDOW)
# right_buf = deque(maxlen=SMOOTH_WINDOW)

# Start/reverse/Stopping logic
speed = 0
normalized_angle_offset = 0
trigger_reverse = False
reverse_start_time = 0
reverse_duration = 0.6  # seconds
reverse_angle = STRAIGHT_CONST
reverse_pause_time = (
    1.3  # seconds to wait after reversing, will not initiate reverse during this period
)
last_reverse_end_time = 0

start_processing = False
stop_flag = False

# Intersection crossing
# current_intersections = 0
# intersection_crossing_start = 0
# intersection_detected = False

# Serial communication
arduino = serial.Serial(port="/dev/ttyUSB0", baudrate=115200, dsrdtr=True)
time.sleep(2)
arduino.write(b"0,-1,95\n")
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

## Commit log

2025-06-15 update error and pid code
    [main.cpp]
2025-06-25 update the arduino main code to removing servo wall follow
2025-08-27 rpi camera calibrated
2025-08-27 update rpi camera calibrated data for wall follow
2025-09-02 add encoder motor
2025-09-08 update encoder motor
2025-09-18 update all 3d file
    [Camera holder.STL, L_font wheel (1).STL, L_font wheel steering (1).STL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]
2025-09-20 start parking using encoder
2025-09-23 parking logic added, updated calibrated values
2025-09-23 reverse region reduced, added lap ignoring if recently reversed
    [contour_workers.py]
2025-09-24 reverse slight left if red obj detected
    [masking_test_pi.py]
2025-09-24 reverse logic steering improved
2025-09-25 Fix image source case in README.md
    Updated image file name in README.md to match the correct case.
2025-10-14 old code
    [lab_dataset.csv]
2025-10-17 stop timer reset on reverse
2025-10-22 add new Design Moedl
    [Camera holder.STL, LED_cover.STL, L_font wheel (1).STL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]
2025-10-22 add new Design Models
    [Camera holder.STL, L_font wheel (1).STL, L_font wheel steering (1).STL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]
2025-10-23 add V2 new Designed 3D Models
    [LED_cover.STL]
2025-11-06 update lap count using gyro
2025-11-06 added camera_settings.json
2025-11-07 camera color picker show hsv colors
2025-11-07 images added and trying to implement odometry
2025-11-07 trying to implement odometry
2025-11-07 Update differential gear description in README
2025-11-08 car driving (for calibration) updated
2025-11-08 arduino code updated (send endcoder and gyro value to raspberry pi)
2025-11-08 applying odometry
2025-11-08 implemented lap count with odometry in open challenge
2025-11-10 ROI changed and arduino ISR logic updated
2025-11-10 odometry error reduction using moving avg
    [odometry.py]
2025-11-10 Led Controll
2025-11-11 main.py updated & LED control added
2025-11-13 Refactor image display and enhance odometry section
    Updated image handling and added odometry description.
2025-11-14 tools updated (added more configs in adjust camera settings)
2025-11-15 arduino encoders code updated
2025-11-15 Enhance README with odometry data details
    Added explanation of odometry data collection and analysis.
2025-11-16 hard turning in tight spaces based on odometry
    [odometry.py, odometry_log.py, odometry_log1.py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]
2025-11-16 improvised reverse function for odometry dependant tight maneuvers
    [odometry.py, parking.py]
2025-11-17 Update motor description and PCB image source
2025-11-17 skip code sequence while reversing
    [lab_dataset.csv]
2025-11-19 added diagram in readme.md
    [L_font wheel steering.STL, L_font wheel.STL, R font wheel steering.STL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]
2025-11-19 values calibrated
2025-11-20 parking path and odometry following priotized
2025-11-21 instant reverse + odometry follow priority
    [img_processing_functions.py, parking.py]
2025-11-21 flowchart added
2025-11-23 added heading in odometry
2025-11-23 tuned for the 2nd round track

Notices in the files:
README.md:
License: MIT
